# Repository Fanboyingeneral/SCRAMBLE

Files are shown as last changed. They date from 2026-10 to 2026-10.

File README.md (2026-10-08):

<div align="center">

# SCRAMBLE

**An autonomous Rubik's Cube solver driven by two bare-metal ATmega32 microcontrollers**

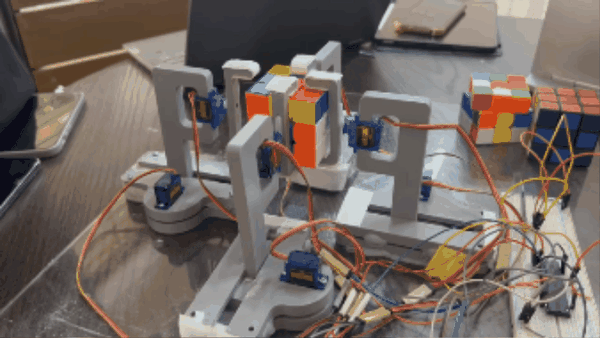
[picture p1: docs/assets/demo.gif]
SCRAMBLE turning a cube face










CSE 316 · Microcontrollers and Microprocessors

</div>

---

## Overview

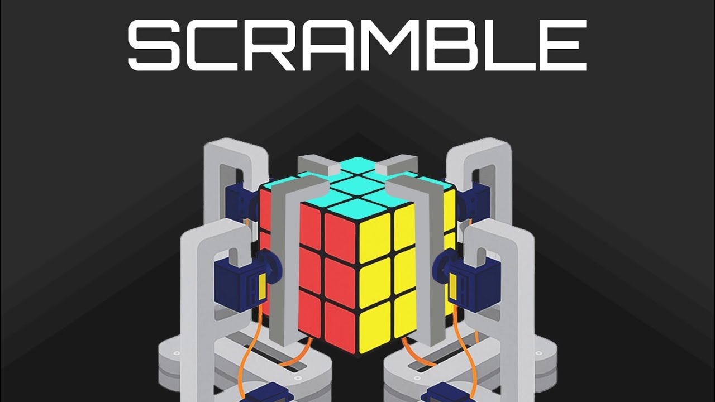
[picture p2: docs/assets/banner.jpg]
SCRAMBLE concept render


SCRAMBLE solves a scrambled 3×3 cube with no human input beyond the initial scan. An Android app reads the cube's state through the phone camera, a laptop computes a solution of at most 20 moves using Kociemba's two-phase algorithm, and the phone relays it over Bluetooth to a rig of eight servos controlled by two ATmega32s.

The firmware is written in plain AVR C against the hardware registers, without Arduino or any third-party libraries.

<br clear="right">

## System architecture

```mermaid
%%{init: {"theme": "base", "themeVariables": {"fontSize": "15px", "lineColor": "#64748b", "edgeLabelBackground": "#ffffff", "textColor": "#0f172a"}, "flowchart": {"curve": "basis", "nodeSpacing": 28, "rankSpacing": 60, "padding": 16}}}%%
flowchart LR
    subgraph PHONE["ANDROID APP"]
        direction TB
        CAM(["Camera scan"]) --> CONF{{"Confirm face"}}
        CONF -. "retake" .-> CAM
        CONF -- "accept ×6" --> STR["54-char facelet string"]
    end

    subgraph LAPTOP["SOLVER SERVER"]
        direction TB
        KOC[["Kociemba two-phase"]] --> SOL["≤ 20-move solution"]
    end

    subgraph RIG["ROBOT RIG"]
        direction TB
        HC(["HC-05 Bluetooth"]) --> M["ATmega32 master"]
        M -- "4 × PWM" --> TOP["4 turret servos · twist"]
        M -- "4 × GPIO" --> S["ATmega32 slave"]
        S -- "4 × PWM" --> BASE["4 base servos · grip"]
    end

    PHONE == "HTTP GET" ==> LAPTOP
    LAPTOP == "solution" ==> PHONE
    PHONE == "Bluetooth SPP" ==> RIG

    classDef app fill:#7c3aed,stroke:#4c1d95,stroke-width:2px,color:#ffffff
    classDef srv fill:#2563eb,stroke:#1e3a8a,stroke-width:2px,color:#ffffff
    classDef bt fill:#0284c7,stroke:#0c4a6e,stroke-width:2px,color:#ffffff
    classDef mcu fill:#0f766e,stroke:#134e4a,stroke-width:2px,color:#ffffff
    classDef servo fill:#f59e0b,stroke:#b45309,stroke-width:2px,color:#1f2937

    class CAM,CONF,STR app
    class KOC,SOL srv
    class HC bt
    class M,S mcu
    class TOP,BASE servo

    style PHONE fill:#f5f3ff,stroke:#7c3aed,stroke-width:2px,color:#5b21b6
    style LAPTOP fill:#eff6ff,stroke:#2563eb,stroke-width:2px,color:#1e40af
    style RIG fill:#f0fdfa,stroke:#0f766e,stroke-width:2px,color:#115e59

    linkStyle 0,1,2 stroke:#7c3aed,stroke-width:2px
    linkStyle 3 stroke:#2563eb,stroke-width:2px
    linkStyle 4,5,6,7 stroke:#0f766e,stroke-width:2px
    linkStyle 8,9 stroke:#2563eb,stroke-width:3px
    linkStyle 10 stroke:#0284c7,stroke-width:3px
```

1. **Scan.** The app guides the user through the faces in U, R, F, D, L, B order. It classifies each sticker by nearest RGB match and asks for confirmation, so a misread face can be retaken.
2. **Solve.** The six faces are serialised into Kociemba's 54-character facelet string and sent to the server, which returns a sequence such as `F2 U3 B2 D1 … (20f)`. The digit is the number of clockwise quarter turns.
3. **Execute.** The phone streams the moves to the HC-05. The master translates each one into a timed sequence of grips and twists shared across both controllers.

## Hardware

| Qty | Component | Role |
|:-:|---|---|
| 2 | ATmega32, internal 1 MHz oscillator | Master and slave controllers |
| 1 | HC-05 Bluetooth module | UART bridge to the phone, 9600 baud |
| 4 | Turret servo (SG90 class) | Rotates a face by 90° |
| 4 | Base servo | Drives a rack and pinion to grip or release |
| 4 | 3D-printed arm assemblies | See [`hardware/`](hardware/) |
| 1 | External 5 V supply | Servo power, common ground with both MCUs |

Four identical arms hold the F, B, L and R faces. Each arm has two degrees of freedom. The base servo turns a pinion along a rack, converting rotation into the linear motion that moves the claw onto or off the cube. The turret servo then rotates the gripped face. The U and D faces have no arm, so the rig reaches them by rolling the whole cube, performing an F turn, and rolling it back.

## Firmware

### Why two microcontrollers

Servos need a steady pulse train, and generating it in hardware keeps the timing jitter-free while the CPU services the UART. The ATmega32 has exactly four hardware PWM outputs:

| Timer | Width | Outputs | Pins |
|---|:-:|---|---|
| Timer 0 | 8-bit | OC0 | PB3 |
| Timer 1 | 16-bit | OC1A, OC1B | PD5, PD4 |
| Timer 2 | 8-bit | OC2 | PD7 |

That allows four servos per chip against the rig's eight. A second ATmega32 was preferred over software PWM or an external PCA9685 driver.

### PWM timing

All three timers run in fast PWM mode with the same period of about 16.4 ms (61 Hz). Timer 1 uses `ICR1 = 2048` with a prescaler of 8, which gives an 8 µs tick and fine positioning. Timers 0 and 2 use a prescaler of 64, giving a 64 µs tick. That coarser step is why their calibration values are small integers such as 7 and 24.

### Master–slave interface

Each base servo has only two positions, so the interface is four logic levels with no protocol at all. The slave polls them every 10 ms and updates its compare registers.

| Master | Slave | Base servo |
|:-:|:-:|---|
| PC0 | PC0 | Front |
| PC1 | PC1 | Back |
| PA2 | PC2 | Left |
| PA3 | PC3 | Right |

A HIGH level means grip and a LOW level means release. Both controllers share a common ground.

### Command set

| Byte | Action | Byte | Action |
|:-:|---|:-:|---|
| `F B L R` | Turret to 0° | `f b l r` | Turret to 90° |
| `W X Y Z` | Base release | `w x y z` | Base grip |
| `S` | Run the stored solve sequence | `A` | Test move (`U3`) |

The single-byte commands allow each servo to be jogged from a Bluetooth terminal, which is how the rig was calibrated. A quarter turn such as `R1` takes four steps: release, pre-rotate the empty claw, grip, then twist. Each step is followed by a 900 ms settling delay. Pin maps and calibration constants are in [`firmware/README.md`](firmware/README.md).

## Getting started

**Solver server**

```bash
cd solver-server
pip install numpy requests
python start_server.py 8080 20 3     # port, max moves, timeout in seconds
python test_client.py                # in a second terminal
```

The first launch generates about 70 MB of pruning tables, which takes several minutes. Later launches load them from disk.

**Android app.** Open [`android-app/`](android-app/) in Android Studio (SDK 36, minimum 24). Set the laptop's LAN address in `MainActivity.kt` under `sendRequestToServer()`, pair the phone with the HC-05, then build.

**Firmware**

```bash
cd firmware
make                 # builds master.hex and slave.hex
make flash-master    # USBasp by default
make flash-slave
```

Both chips run on the factory-default fuses. Calibrate the servo constants for your hardware before the first run.

## Repository structure

| Path | Contents |
|---|---|
| [`firmware/`](firmware/) | Master and slave controllers, Makefile |
| [`android-app/`](android-app/) | Scanner and controller app used in the demo |
| [`solver-server/`](solver-server/) | Kociemba's two-phase solver (vendored) and a test client |
| [`hardware/`](hardware/) | Print-ready STLs, FreeCAD sources, assembly drawings |
| [`docs/`](docs/) | Proposal decks and a [provenance map](docs/PROVENANCE.md) of the original working folder |
| [`archive/`](archive/) | Superseded prototypes and experiments, [catalogued here](archive/README.md) |
| [`coursework/`](coursework/) | Unrelated CSE 316 coursework |

## Development history

```mermaid
timeline
    title July 2025
    Jul 02 : Arm parts exported for printing, claw redesigned
    Jul 06 : Arduino reference design studied
    Jul 10 : Reference ported to ATmega32 C
    Jul 13 : Servo bring-up and calibration
    Jul 14 : Slave controller finalised
    Jul 23 : Camera scanner prototype
           : Manual-entry app with solver and Bluetooth
    Jul 26 : Master controller finalised
    Jul 28 : Final app
    Jul 29 : Demo
```

The project began from an open-source Arduino solver that ran a CFOP solver on the microcontroller and drove its servos through a PCA9685. Three decisions moved it away from that design:

- **Solving moved off the chip.** The two-phase algorithm caps solutions at 20 moves, and each move costs several seconds of servo time.
- **The PCA9685 was replaced by a second ATmega32**, which kept all servo control in native timer hardware.
- **Scanning kept a human in the loop.** An intermediate version used manual colour entry. The final app scans with the camera and asks for confirmation of each face.

## Known limitations

- The server address is hard-coded in the app.
- Colour references are tuned to one cube under one lighting setup.
- Motion is open-loop with fixed delays, so a failed grip goes undetected.

## Acknowledgements

- [**RubiksCube-TwophaseSolver**](https://github.com/hkociemba/RubiksCube-TwophaseSolver) by Herbert Kociemba (GPL-3.0), included unmodified in `solver-server/`.
- **Arduino-RubikSolver** (public domain), the source of the arm's FreeCAD design. We re-exported the parts for printing and redesigned the claw. A snapshot is kept in [`archive/upstream-reference/`](archive/upstream-reference/).

## Team

| Name | Student ID |
|---|:-:|
| Sakif Naieb Raiyan | 2105065 |
| Sayaad Muzahid Masfi | 2105066 |
| Aurchi Chowdhury | 2105083 |

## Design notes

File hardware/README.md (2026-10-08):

# 🔩 Hardware

| Folder | Contents |
|---|---|
| [`stl-print-ready/`](stl-print-ready/) | ⭐ **The STLs we printed.** Exported 2 Jul 2025. `Claw2.stl` is our redesigned claw |
| [`freecad-source/`](freecad-source/) | FreeCAD 0.17 sources for each part. Most are identical to the *Arduino-RubikSolver* project's `CAD/Final cuts` |
| [`blueprints/`](blueprints/) | Assembly and part drawings (PDF) from the same upstream project |

## One arm = 6 parts (×4 arms)

| Part | Job |
|---|---|
| `Base-bottom` / `Base-top` | Frame that holds the base servo and guides the rack |
| `Gear` | Pinion on the base servo horn |
| `Rack` | Slides in and out as the gear turns, turning **rotation into linear motion** |
| `Turret` | Rides on the rack and holds the turret servo |
| `Claw` | Mounted on the turret servo horn; grips and twists one face |

`servo-base.FCStd` and `cube.FCStd` (a reference cube for fitting) are in `freecad-source/`. An earlier STL export of every part, including the cube, is in [`../archive/hardware/stl-first-export/`](../archive/hardware/stl-first-export/).

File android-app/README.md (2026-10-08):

# 📱 SCRAMBLE Android app

The phone app used in the demo. It scans the cube, gets a solution from the laptop server and relays it to the rig over Bluetooth.

> The project and package are still called `RubiksCubeSolverWithoutCamera` / `com.example.rubikscubesolverwithoutcamera` for historical reasons. It started as a manual colour-entry app ([archive](../archive/android/02-manual-color-entry/)) and gained the camera later. Renaming the package is safe if you want to.

## Flow

```
Scan face ──▶ Confirm grid ──▶ (Retake | Accept) ──▶ … ×6 ──▶ GET solver ──▶ Solution screen
                                                                              ├─ Program  (sends "P")
                                                                              ├─ Send next move (e.g. "F2", last one gets ")")
                                                                              └─ Execute  (sends "S")
```

| Stage | Implementation |
|---|---|
| Camera | CameraX `Preview` + `ImageAnalysis` (keep-only-latest) |
| Sampling | 9 square ROIs at the centre of each grid cell, averaged RGB |
| Classification | Nearest neighbour (Euclidean RGB) against 6 reference colours |
| Face order | **U R F D L B**, which is Kociemba's facelet order |
| Colour scheme | U white · R blue · F red · D yellow · L green · B orange |
| Server call | OkHttp `GET http://<ip>:8080/<54 chars>`, solution parsed from `<body>` |
| Bluetooth | Bonded device named **`HC-05`**, insecure RFCOMM, SPP UUID `00001101-…-00805F9B34FB` |

## Configure

| What | Where |
|---|---|
| Laptop IP | `MainActivity.kt` → `sendRequestToServer()` (currently `172.20.10.12`) |
| Reference colours | `MainActivity.kt` → `referenceColorsRgb`. Tune these for your cube and lighting |
| Bluetooth name | `MainActivity.kt` → `sendBluetoothCommand()` → `deviceName` |

Cleartext HTTP to the LAN server is allowed through `res/xml/network_security_config.xml`.

## Build

Open this folder in Android Studio (compile/target SDK 36, min SDK 24) and run. Android Studio regenerates `local.properties`, which is git-ignored.

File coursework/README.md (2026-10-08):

# 📚 Coursework (not part of SCRAMBLE)

Other CSE 316 sessional material that lived in the same folder as the project. It's kept for completeness and has **no relation to the cube solver**.

| Folder | Contents |
|---|---|
| [`assembly-online-1/`](assembly-online-1/) | 8086 assembly solutions (emu8086) and the online question sheet |
| [`assembly-offlines/`](assembly-offlines/) | Assembly offline/online problem statements (PDF) |
| [`experiments/`](experiments/) | Lab experiment sheets (LED matrix, Experiment 2) and a demo deck |

The emu8086 installation, its build artifacts and the `Utilities` DLL were not copied. They remain in the raw source folder.

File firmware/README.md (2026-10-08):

# ⚙️ Firmware: ATmega32 master + slave

Bare-metal AVR C with direct register access and no Arduino core. Both chips run on the **internal 1 MHz RC oscillator** (factory fuses).

| File | Chip | Drives |
|---|---|---|
| [`master/master_controller.c`](master/master_controller.c) | Master | HC-05 UART, 4 turret servos, 4 lines to the slave, move choreography |
| [`slave/slave_controller.c`](slave/slave_controller.c) | Slave | 4 base (grip) servos, mirroring the master's 4 lines |

## Build and flash

Requires `avr-gcc`, `avr-libc` and `avrdude` (or Microchip Studio).

```bash
make                 # → master.hex, slave.hex
make flash-master    # default programmer: USBasp
make flash-slave
make flash-master PROGRAMMER=stk500v1 PORT=COM5   # override
```

## Why 4 servos per chip

The ATmega32 has four hardware PWM outputs: **OC0** (PB3), **OC1A** (PD5), **OC1B** (PD4) and **OC2** (PD7). Timer 1 is 16-bit and drives two of them. Timers 0 and 2 are 8-bit and drive one each. Eight servos therefore need two chips.

## PWM configuration

```c
// Timer 1: Fast PWM, TOP = ICR1 (mode 14), prescaler 8 → 8 µs/tick, 2049 ticks ≈ 16.4 ms
TCCR1A = (1<<WGM11) | (1<<COM1A1) | (1<<COM1B1);
TCCR1B = (1<<WGM13) | (1<<WGM12) | (1<<CS11);
ICR1   = 2048;

// Timer 2: Fast PWM 8-bit, prescaler 64 → 64 µs/tick, 256 ticks ≈ 16.4 ms
TCCR2 = (1<<WGM21) | (1<<WGM20) | (1<<COM21) | (1<<CS22);

// Timer 0: Fast PWM 8-bit, prescaler 64 → same 16.4 ms frame
TCCR0 = (1<<WGM01) | (1<<WGM00) | (1<<COM01) | (1<<CS01) | (1<<CS00);
```

Pulse width = `OCRx × tick`. For example, `OCR1B = 75` gives 600 µs and `OCR1B = 210` gives 1.68 ms.

## Calibration constants

Measured on our rig. **Re-measure these for yours.**

| Servo | Register | 0° / min | 90° / max |
|---|---|:-:|:-:|
| Turret Front | master `OCR1B` | 75 | 210 |
| Turret Back | master `OCR1A` | 78 | 204 |
| Turret Left | master `OCR2` | 7 | 24 |
| Turret Right | master `OCR0` | 8 | 24 |
| Base Front | slave `OCR1B` | 70 | 230 |
| Base Back | slave `OCR1A` | 120 | 280 |
| Base Left | slave `OCR2` | 10 | 30 |
| Base Right | slave `OCR0` | 10 | 30 |

Use the single-byte jog commands (`F`/`f`, `W`/`w`, …) from a Bluetooth serial terminal to find each value.

## Master → slave wiring

| Master | Slave | Base servo |
|:-:|:-:|---|
| PC0 | PC0 | Front |
| PC1 | PC1 | Back |
| PA2 | PC2 | Left |
| PA3 | PC3 | Right |
| GND | GND | *common ground* |

> The header comment in `master_controller.c` says PC0–PC3, but the code drives **PC0, PC1, PA2, PA3**. The table above follows the code.

## Move notation

The solver outputs moves as `<face><n>`, where `n` is the number of clockwise quarter turns (`1` = 90°, `2` = 180°, `3` = 270°, i.e. counter-clockwise). `execute_sequence()` parses that format directly and stops at `(` (the `(20f)` length suffix).

| Move | Implementation |
|---|---|
| `F` `B` `L` `R` + 1/2/3 | Release → pre-rotate → grip → twist, using the face's own arm |
| `U` + n | `Rotate_top()` → `F` + n → `Rotate_bottom()` |
| `D` + n | `Rotate_bottom()` → `F` + n → `Rotate_top()` |

Each primitive step is followed by `_delay_ms(900)`.

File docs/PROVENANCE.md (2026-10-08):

# 🧭 Provenance: raw folder → repo

This repo was assembled from the original, unorganised `CSE 316/` working folder, which is preserved untouched. The tables below show where everything came from and what was deliberately left out.

## Copied

| Raw path | Repo path |
|---|---|
| `maxresdefault.jpg` | `docs/assets/banner.jpg` |
| `Project/Project Proposal Presentation.pdf`, `Project/Updated Proposal.pdf` | `docs/proposal/` |
| `Project/Arduino-RubikSolver-master/arduino files/a_constants/master_controller.c` | `firmware/master/` |
| `Project/Arduino-RubikSolver-master/arduino files/a_constants/slave_controller.c` | `firmware/slave/` |
| `RubiksCubeSolverWithoutCamera/` | `android-app/` |
| `Project_Web_Server/RubiksCube-TwophaseSolver-master/` | `solver-server/` (`README.md` → `UPSTREAM_README.md`) |
| `Project_Web_Server/test_client.py` | `solver-server/test_client.py` |
| `Project/Print Ready 3D Files/` | `hardware/stl-print-ready/` |
| `Project/Original 3D Files/` | `hardware/freecad-source/` |
| `Project/rubick-*.pdf` | `hardware/blueprints/` |
| `Project_Android_App/` | `archive/android/01-camera-hsv-client/` |
| `FinalVersionAttempt_v1/` | `archive/android/02-manual-color-entry/` |
| `BluetoothTestApp/` | `archive/android/03-bluetooth-test/` |
| `…/a_constants/*_atmega32.c` (except motor tests) | `archive/firmware/atmega32-cfop-port/` |
| `…/a_constants/{top_motors,base_motors,new_task}_atmega32.c` | `archive/firmware/motor-tests/` |
| `…/arduino files/Solver/solver.py` | `archive/firmware/solver-smoke-test/` |
| `Project/3D Files/All3D_stl/` | `archive/hardware/stl-first-export/` |
| `Project/6190212806561875445.jpg`, `Project/c3RlZCZ3PTc0MA.png` | `archive/proposal-assets/` |
| `Project/Arduino-RubikSolver-master/` (sources, CAD, blueprints, photos) | `archive/upstream-reference/Arduino-RubikSolver/` |
| `Online Prep/Online 1/*.asm`, `Online q.pdf` | `coursework/assembly-online-1/` |
| `Offlines/*.pdf` | `coursework/assembly-offlines/` |
| `Experiments/*.pdf`, `demo.pptx` | `coursework/experiments/` |

## Not copied (still in the raw folder)

| Raw path | Why |
|---|---|
| `Project/Final Demo.mov` (569 MB) | Over GitHub's 100 MB limit. It's [on YouTube](https://youtu.be/4RdSLmTVIiQ) |
| `Project/arduino-ide_nightly-…zip` (196 MB) | Third-party installer |
| `emu8086/`, `emu8086v408r.exe` | Third-party tool installation |
| `Experiments/Utilities*` | Third-party binary |
| `Project/IMG_20190305_233856.jpg` | Duplicate of an upstream photo (kept in `archive/upstream-reference/…/CAD/photos/`) |
| `Project/3D Files/All3D_stl.zip` | Zip of `All3D_stl/`, which is copied unzipped |
| `Project/Atmel/` | Empty |
| Upstream `android App/java/` + native libs (~1.5 GB) | Bundled OpenCV Android SDK |
| Upstream `CAD/CNC cutting media/*.mp4` (~230 MB) | Upstream build videos |
| Upstream `arduino files/Solver/` tables, `Project_Web_Server/…/twophase/` (~70 MB each) | Generated solver tables; rebuilt on first run |
| `Online Prep/Online 1/noname.exe*` | emu8086 build artifacts and backups |
| `build/`, `.gradle/`, `.idea/`, `.kotlin/`, `__pycache__/`, `local.properties` | Generated or machine-specific |

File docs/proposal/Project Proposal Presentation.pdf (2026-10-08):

# Scramble

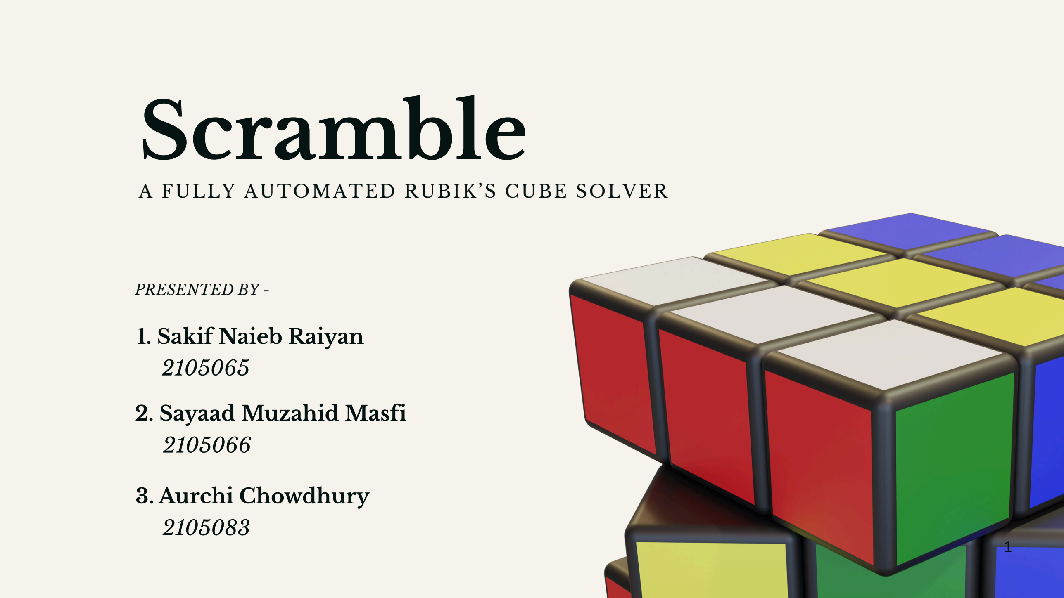
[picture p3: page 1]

A FULLY AUTOMATED RUBIK’S CUBE SOLVER

PRESENTED BY -

1

### 1. Sakif Naieb Raiyan

2105065

### 2. Sayaad Muzahid Masfi

### 3. Aurchi Chowdhury

2105066

2105083

# MOTIVATION

2

## PROBLEM STATEMENT

DESIGN AND DEVELOP AN AUTOMATED RUBIK’S CUBE SOLVER USING A MICROCONTROLLER-BASED SYSTEM THAT CAN PHYSICALLY MANIPULATE THE CUBE AND TRACK SOLVE TIME, WITH USER INPUT PROVIDED VIA A MOBILE INTERFACE

3

## SIGNIFICANCE

4

The Rubik’

s Cube is a globally recognized puzzle that represents a challenge in both logic and dexterity.

Automating its solution not only demonstrates practical applications of embedded systems, robotics, and computer vision, but also showcases how mechanical and software components can work together to solve complex problems.

This project bridges the gap between theoretical concepts and real-world implementation, making it an excellent learning opportunity in the fields of mechatronics and embedded systems.

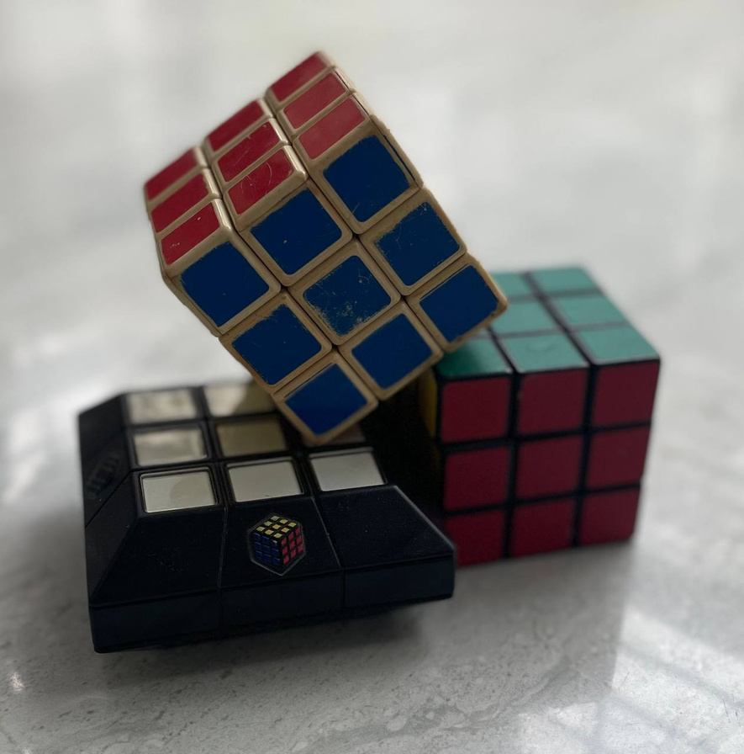
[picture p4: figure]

## PERSONAL INTEREST

5

All three of us were fascinated by the Rubik’

s Cube back in 7th grade, when we each owned multiple and took the time to learn how to solve it.
That early interest sparked our curiosity in problem-solving and logical thinking, and eventually inspired this project. This project is especially interesting to us as it showcases how a childhood curiosity can grow into an engineering challenge.

One of our team members dug up some of his old Rubik’

s cubes

# EQUIPMENT

6

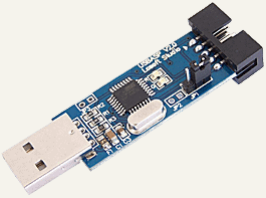
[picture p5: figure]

USBASP

3

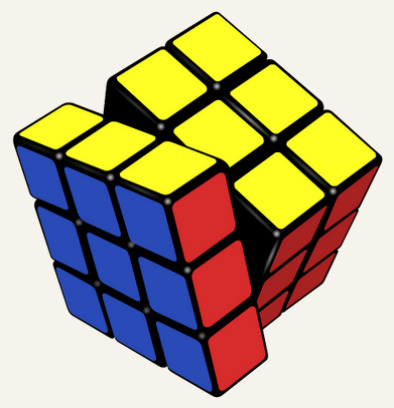
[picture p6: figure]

Rubik’

s Cube

1

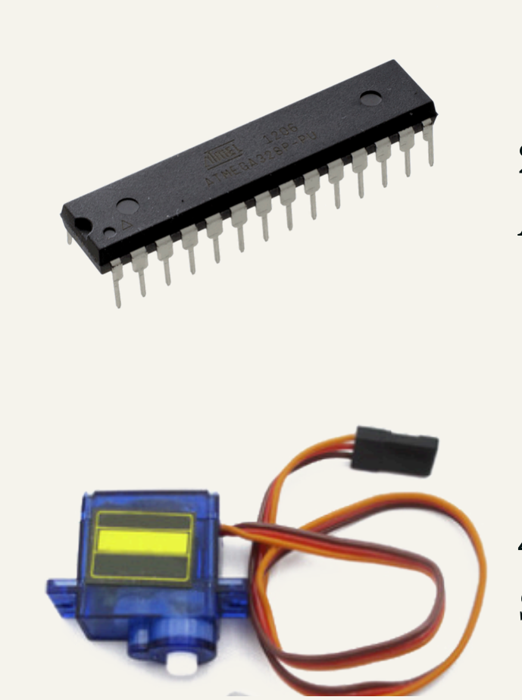
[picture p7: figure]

SG90 Servo Motor

4

ATMega32

2

## Hardware List

7

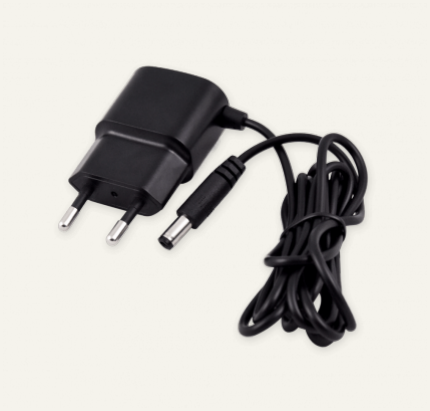
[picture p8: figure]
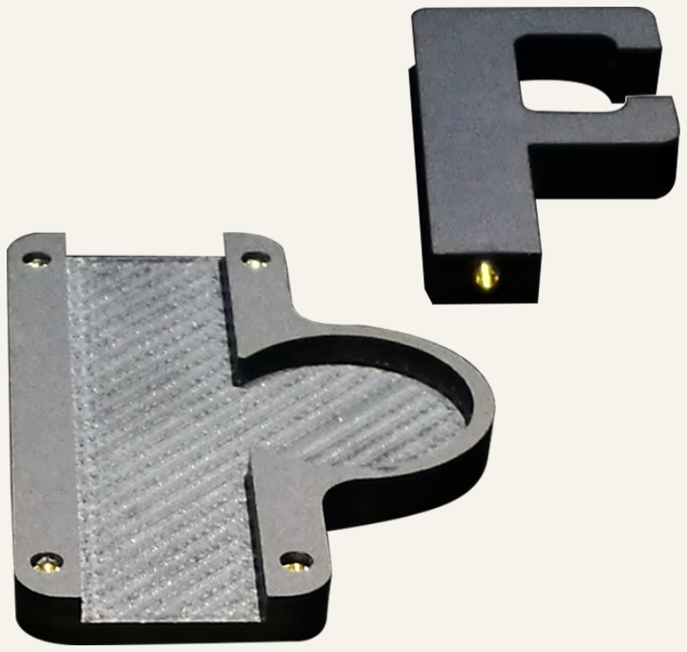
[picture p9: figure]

8

Power Supply

7

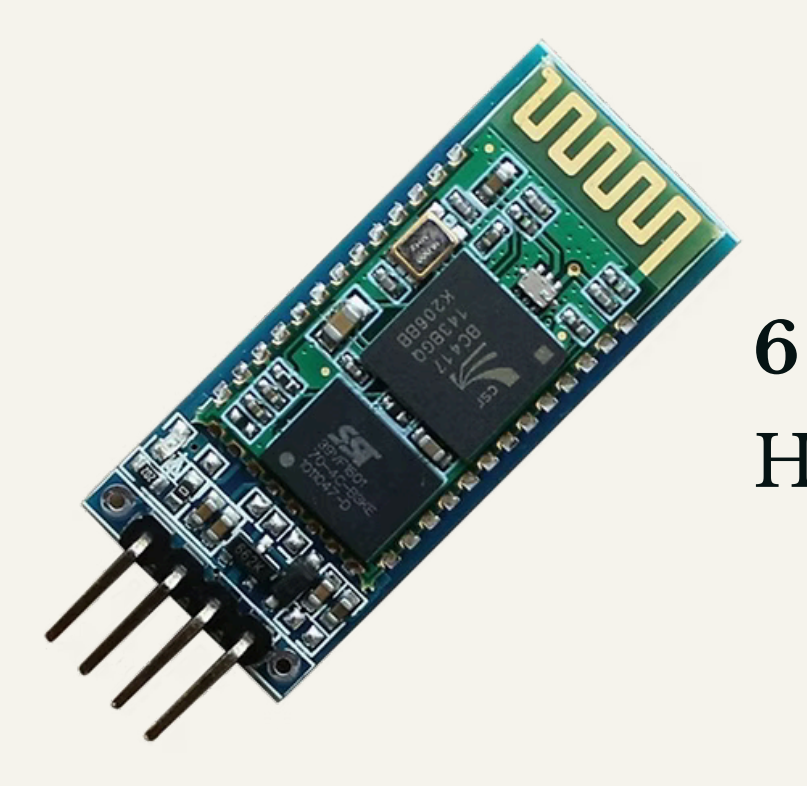
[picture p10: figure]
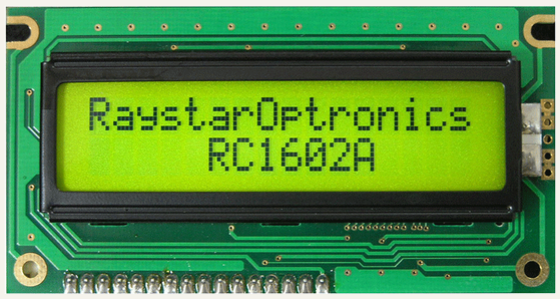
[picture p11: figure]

LCD 16x2 Display

5

Acrylic Printed
Mechanical Arm

8

HC-06 Bluetooth Module

## Hardware List

# SCHEMATIC

9

## HIGH LEVEL DIAGRAM

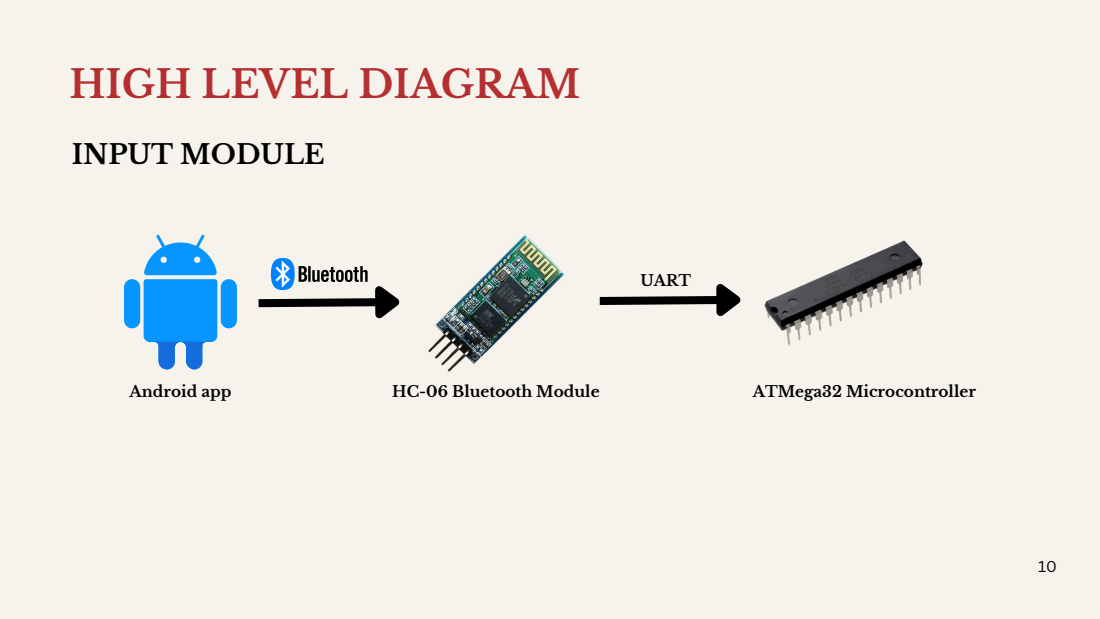
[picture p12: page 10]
Android app; HC-06 Bluetooth Module; UART; ATMega32 Microcontroller; INPUT MODULE

11

## HIGH LEVEL DIAGRAM

PROCESSING AND OUTPUT MODULE

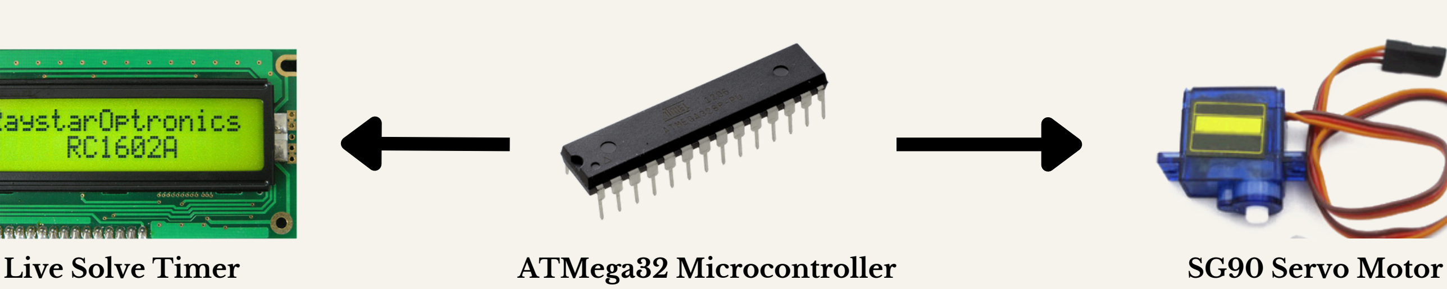
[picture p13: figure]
ATMega32 Microcontroller; Live Solve Timer; SG90 Servo Motor
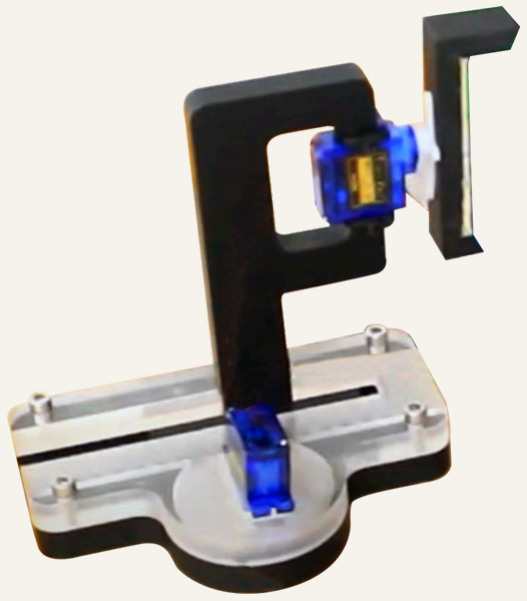
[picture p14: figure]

Mechanical Arm

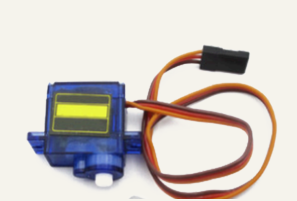
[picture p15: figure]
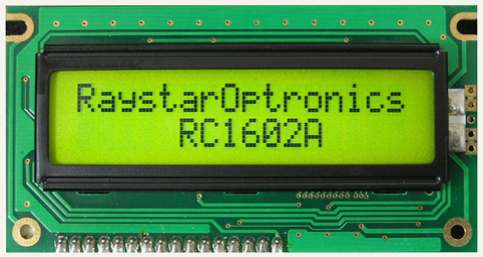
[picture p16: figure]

12

# Explanation

Android App: Captures the initial state of the Rubik’

s
Cube using the phone camera and sends the color configuration to the microcontroller via Bluetooth. HC-06 Bluetooth Module: Acts as a wireless communication bridge between the Android app and the ATmega32 microcontroller using UART.
ATmega32 Microcontroller: The core of the system that receives input from the Bluetooth module, calculates the solution (or controls motors based on a received solve sequence), and drives the mechanical components.

13

# Explanation

LCD Timer Display: Displays the time taken to complete the solve and updates live during operation. Servo/Stepper Motors: Physically manipulate the Rubik’

s Cube to perform the solving moves. Power Supply: Provides appropriate voltage and current to all electronic components and motors.
Mechanical Arm (Acrylic Structure): Holds and rotates the Rubik’

s Cube based on motor control, built from custom-cut acrylic sheets.

14

# PROCESS

15

# Expected Outcome

The final project is expected to successfully scan the state of a standard 3×3 Rubik’

s Cube, compute the optimal or near-optimal solution using a solving algorithm, and physically solve the cube using motors controlled by an ATMega32 microcontroller.

# Step-by-Step Plan

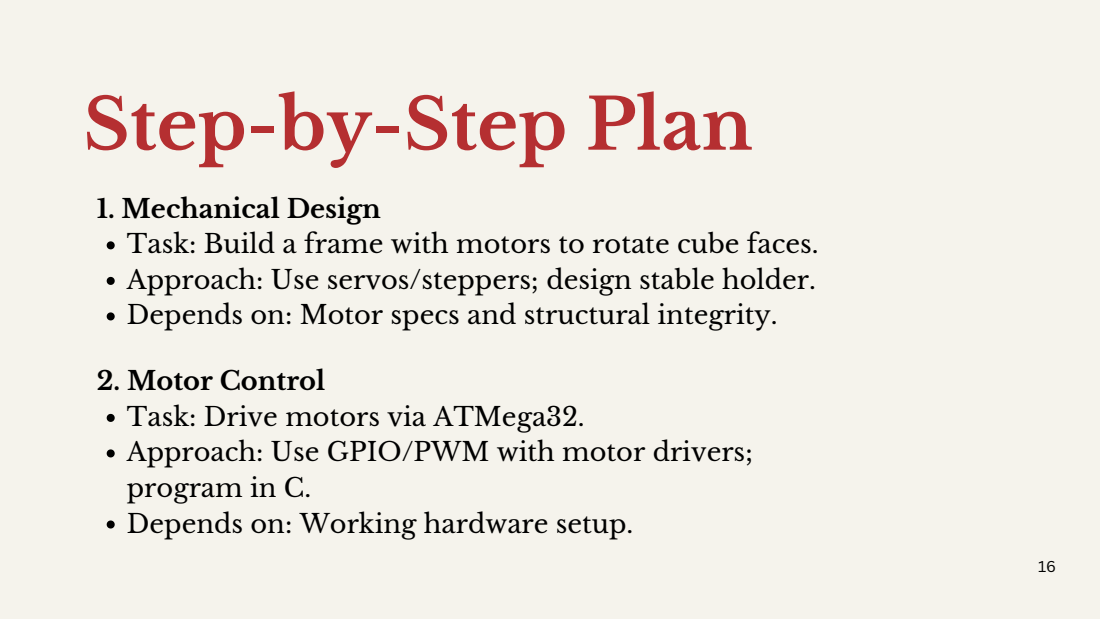
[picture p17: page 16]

1. Mechanical Design
Task: Build a frame with motors to rotate cube faces.
Approach: Use servos/steppers; design stable holder.
Depends on: Motor specs and structural integrity.

2. Motor Control
Task: Drive motors via ATMega32.
Approach: Use GPIO/PWM with motor drivers;
program in C.
Depends on: Working hardware setup.

# Step-by-Step Plan

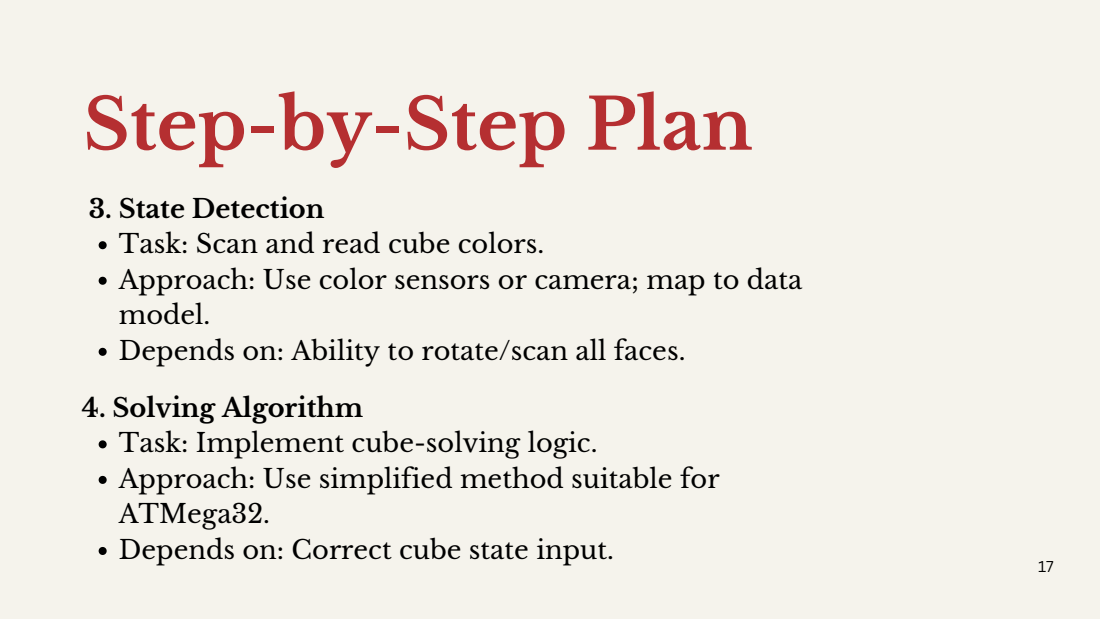
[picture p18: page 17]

3. State Detection
Task: Scan and read cube colors.
Approach: Use color sensors or camera; map to data
model.
Depends on: Ability to rotate/scan all faces.
4. Solving Algorithm
Task: Implement cube-solving logic.
Approach: Use simplified method suitable for
ATMega32.
Depends on: Correct cube state input.

# Step-by-Step Plan

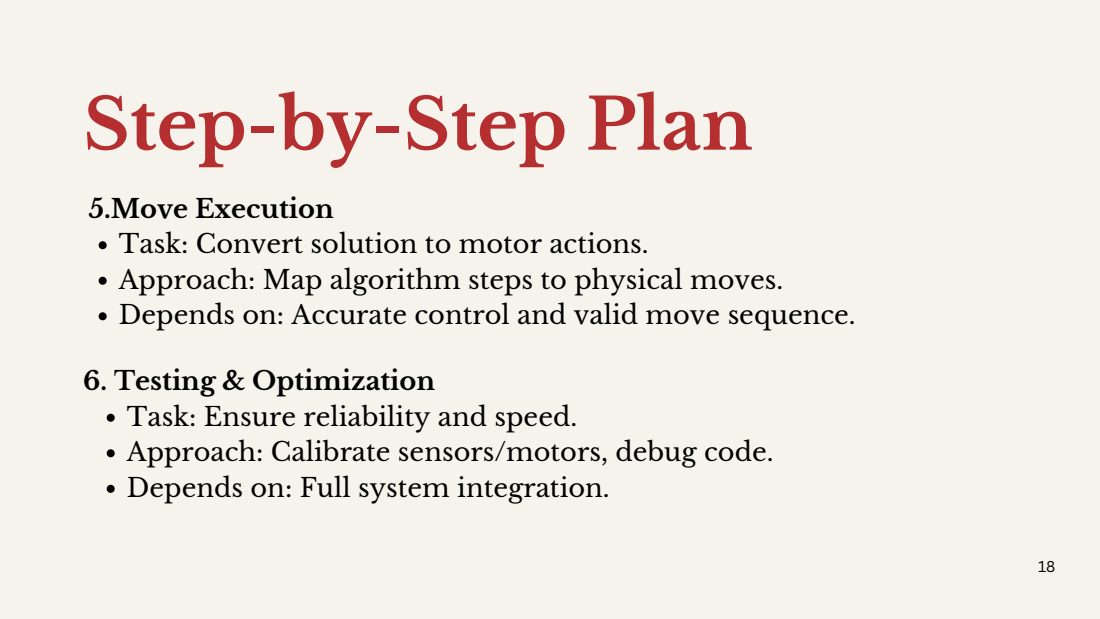
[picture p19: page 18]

5.Move Execution
Task: Convert solution to motor actions.
Approach: Map algorithm steps to physical moves.
Depends on: Accurate control and valid move sequence.

6. Testing & Optimization
Task: Ensure reliability and speed.
Approach: Calibrate sensors/motors, debug code.
Depends on: Full system integration.

# CHALLENGES AND FUTURE DIRECTIONS

19

# Challenges

### 1. Motor Control and Precision 2. Building and Assembling the Mechanical Parts 3. Cube State Detection 4. Processing Limitations of ATMega32

20

21

# Future Scope

## Scalability and Optimization

The project could be enhanced to support faster solve times through optimized algorithms or by upgrading to a more powerful microcontroller while maintaining the ATMega32 for simpler tasks.

22

# Future Scope

## Integrating Advanced Visualization Systems and UI

Adding a small display or mobile app interface could allow users to interact with the system, view solving steps, or select different solving modes

23

# Future Scope

## Real-World Applications Beyond the Classroom

STEM Demonstration: Can be used in robotics clubs, science fairs, or tech exhibitions to demonstrate automation and embedded system applications.

Educational Tool: Helps in teaching control systems, embedded programming, and algorithms.

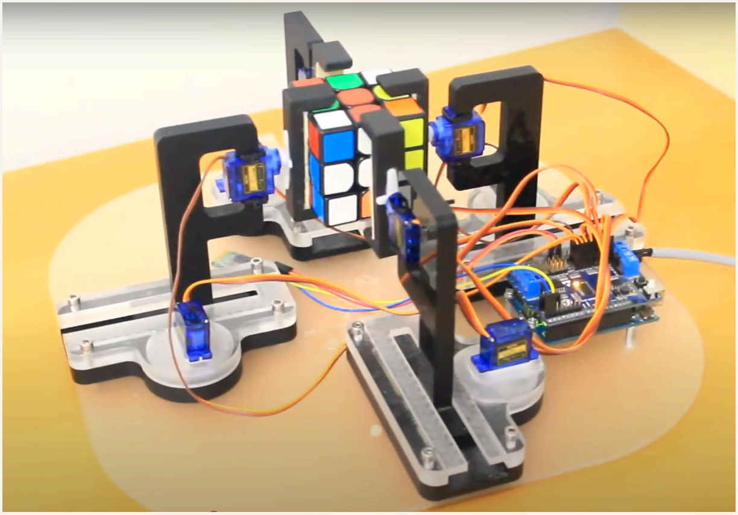
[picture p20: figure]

24

# Inspiration From

Links to the-YouTube video (https://www.youtube.com/watch?v=ZHaAKOHkDEo&t=1s&ab_channel=Eman)
Github Repository (https://github.com/EmanGM/Arduino-RubikSolver)

25

# THANK YOU!

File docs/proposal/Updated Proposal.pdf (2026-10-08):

# Scramble


A FULLY AUTOMATED RUBIK’S CUBE SOLVER

PRESENTED BY -

1

### 1. Sakif Naieb Raiyan

2105065

### 2. Sayaad Muzahid Masfi

### 3. Aurchi Chowdhury

2105066

2105083

# MOTIVATION

2

## PROBLEM STATEMENT

DESIGN AND DEVELOP AN AUTOMATED RUBIK’S CUBE SOLVER USING A MICROCONTROLLER-BASED SYSTEM THAT CAN PHYSICALLY MANIPULATE THE CUBE AND TRACK SOLVE TIME, WITH USER INPUT PROVIDED VIA A MOBILE INTERFACE

3

## SIGNIFICANCE

4

The Rubik’

s Cube is a globally recognized puzzle that represents a challenge in both logic and dexterity.

Automating its solution not only demonstrates practical applications of embedded systems, robotics, and computer vision, but also showcases how mechanical and software components can work together to solve complex problems.

This project bridges the gap between theoretical concepts and real-world implementation, making it an excellent learning opportunity in the fields of mechatronics and embedded systems.


## PERSONAL INTEREST

5

All three of us were fascinated by the Rubik’

s Cube back in 7th grade, when we each owned multiple and took the time to learn how to solve it.
That early interest sparked our curiosity in problem-solving and logical thinking, and eventually inspired this project. This project is especially interesting to us as it showcases how a childhood curiosity can grow into an engineering challenge.

One of our team members dug up some of his old Rubik’

s cubes

# EQUIPMENT

6


USBASP

3


Rubik’

s Cube

1


SG90 Servo Motor

4

ATMega32

2

## Hardware List

7


8

Power Supply

7


LCD 16x2 Display

5

Acrylic Printed
Mechanical Arm

8

HC-05 Bluetooth Module

## Hardware List

# SCHEMATIC

9

## HIGH LEVEL DIAGRAM

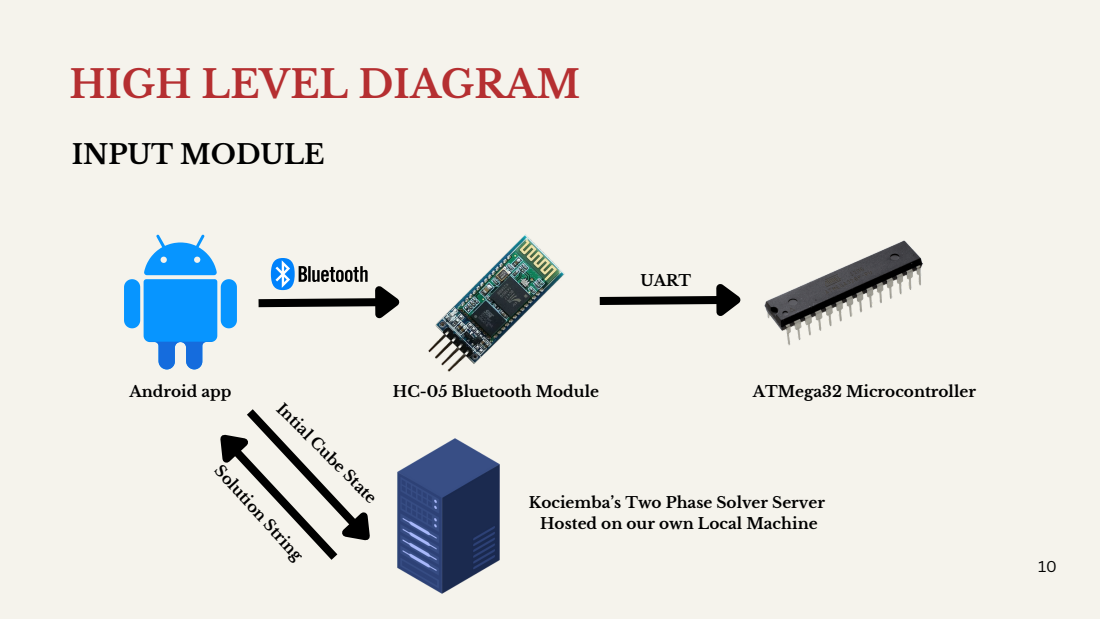
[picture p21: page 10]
Android app; HC-05 Bluetooth Module; UART; ATMega32 Microcontroller; INPUT MODULE; Solution String

Intial Cube State

Kociemba’s Two Phase Solver Server
Hosted on our own Local Machine

11

## HIGH LEVEL DIAGRAM

PROCESSING AND OUTPUT MODULE

ATMega32 Microcontroller; Live Solve Timer; SG90 Servo Motor

Mechanical Arm


12

# Explanation

Android App: Captures the initial state of the Rubik’

s
Cube using the phone camera and sends the color configuration to the microcontroller via Bluetooth. HC-06 Bluetooth Module: Acts as a wireless communication bridge between the Android app and the ATmega32 microcontroller using UART.
ATmega32 Microcontroller: The core of the system that receives input from the Bluetooth module, calculates the solution (or controls motors based on a received solve sequence), and drives the mechanical components.

13

# Explanation

LCD Timer Display: Displays the time taken to complete the solve and updates live during operation. Servo/Stepper Motors: Physically manipulate the Rubik’

s Cube to perform the solving moves. Power Supply: Provides appropriate voltage and current to all electronic components and motors.
Mechanical Arm (Acrylic Structure): Holds and rotates the Rubik’

s Cube based on motor control, built from custom-cut acrylic sheets.

14

# PROCESS

15

# Expected Outcome

The final project is expected to successfully scan the state of a standard 3×3 Rubik’

s Cube, compute the optimal or near-optimal solution using a solving algorithm, and physically solve the cube using motors controlled by an ATMega32 microcontroller.

# Step-by-Step Plan


1. Mechanical Design
Task: Build a frame with motors to rotate cube faces.
Approach: Use servos/steppers; design stable holder.
Depends on: Motor specs and structural integrity.

2. Motor Control
Task: Drive motors via ATMega32.
Approach: Use GPIO/PWM with motor drivers;
program in C.
Depends on: Working hardware setup.

# Step-by-Step Plan


3. State Detection
Task: Scan and read cube colors.
Approach: Use color sensors or camera; map to data
model.
Depends on: Ability to rotate/scan all faces.
4. Solving Algorithm
Task: Implement cube-solving logic.
Approach: Use simplified method suitable for
ATMega32.
Depends on: Correct cube state input.

# Step-by-Step Plan


5.Move Execution
Task: Convert solution to motor actions.
Approach: Map algorithm steps to physical moves.
Depends on: Accurate control and valid move sequence.

6. Testing & Optimization
Task: Ensure reliability and speed.
Approach: Calibrate sensors/motors, debug code.
Depends on: Full system integration.

# CHALLENGES AND FUTURE DIRECTIONS

19

# Challenges

### 1. Motor Control and Precision 2. Building and Assembling the Mechanical Parts 3. Cube State Detection 4. Processing Limitations of ATMega32

20

21

# Future Scope

## Scalability and Optimization

The project could be enhanced to support faster solve times through optimized algorithms or by upgrading to a more powerful microcontroller while maintaining the ATMega32 for simpler tasks.

22

# Future Scope

## Integrating Advanced Visualization Systems and UI

Adding a small display or mobile app interface could allow users to interact with the system, view solving steps, or select different solving modes

23

# Future Scope

## Real-World Applications Beyond the Classroom

STEM Demonstration: Can be used in robotics clubs, science fairs, or tech exhibitions to demonstrate automation and embedded system applications.

Educational Tool: Helps in teaching control systems, embedded programming, and algorithms.


24

# Inspiration From

Links to the-YouTube video (https://www.youtube.com/watch?v=ZHaAKOHkDEo&t=1s&ab_channel=Eman)
Github Repository (https://github.com/EmanGM/Arduino-RubikSolver)

25

# MEET THE TEAM

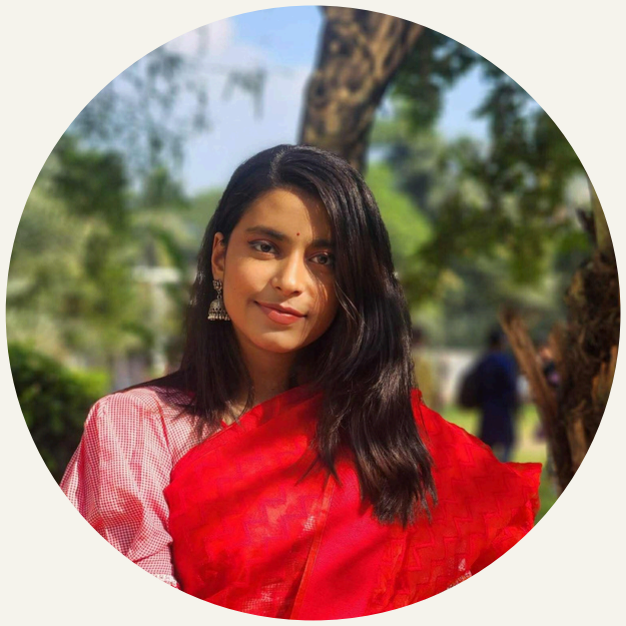
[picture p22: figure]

Aurchi Chowdhury
2105083

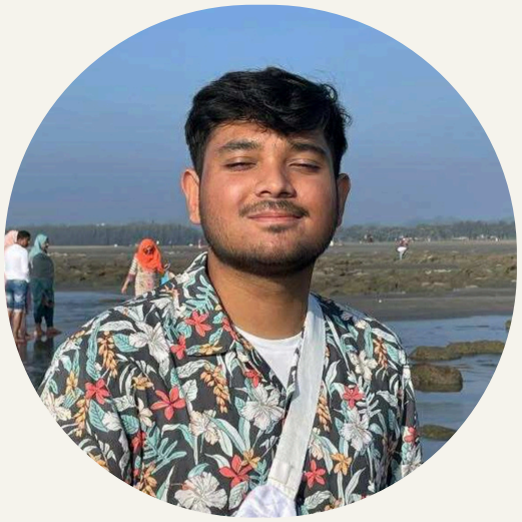
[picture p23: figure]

Sakif Naieb Raiyan
2105065

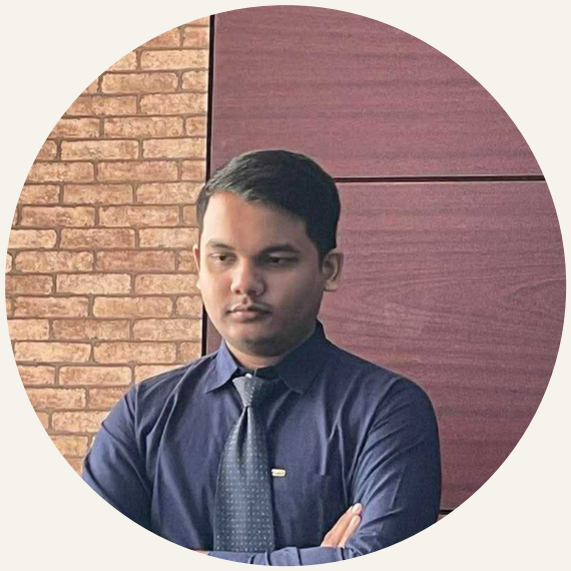
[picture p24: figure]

Sayaad Muzahid Masfi
2105066

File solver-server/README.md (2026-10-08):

# 🧠 Solver server

This is **[Herbert Kociemba's RubiksCube-TwophaseSolver](https://github.com/hkociemba/RubiksCube-TwophaseSolver)**, vendored **unmodified** and licensed under **GPL-3.0** (see [`LICENSE`](LICENSE)). The original documentation is in [`UPSTREAM_README.md`](UPSTREAM_README.md).

The only SCRAMBLE addition is [`test_client.py`](test_client.py).

## Run

```bash
pip install numpy requests
python start_server.py 8080 20 3    # port, max solution length, search timeout (s)
```

The first start generates the pruning and move tables (~70 MB) into `twophase/`. This takes a while and only happens once. The folder is git-ignored.

## API

```
GET http://<host>:8080/<54-char facelet string in URFDLB order>
→ <html>…<body>F2 U3 F2 U3 B2 D1 L2 U2 F2 L1 B3 L1 F3 U1 B3 D1 L3 F3 R1 B1 (20f)</body></html>
```

## Test

```bash
python test_client.py
```

This sends a fixed scramble to `localhost:8080` and prints the solution.

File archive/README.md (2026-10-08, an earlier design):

# 🧪 Archive: explorations and dead ends

**Nothing in this folder is part of the final SCRAMBLE build.** These are the experiments, ports and test apps that led to it. They are kept because they show how the design evolved, and some (like the motor tests) are handy for bring-up.

Legend: 🟢 directly led to the final design · 🟡 partly reused · 🔴 abandoned · 📖 third-party reference

---

## 📱 `android/`

| Folder | Date | Status | What it is |
|---|---|:-:|---|
| [`01-camera-hsv-client/`](android/01-camera-hsv-client/) | 23 Jul | 🟡 | **First app** (`RubiksSolverClient`). CameraX scanner that *learns* reference colours in a calibration pass (HSV), then scans. Scanning only: no solver call and no Bluetooth yet. The camera and ROI code were carried into the final app |
| [`02-manual-color-entry/`](android/02-manual-color-entry/) | 23–26 Jul | 🟡 | **`FinalVersionAttempt_v1`**. Drops the camera: you tap stickers on a grid with a colour palette. Adds the solver HTTP call and HC-05 Bluetooth sending. The final app is this project plus the camera back. That's where the name *RubiksCubeSolverWithoutCamera* comes from |
| [`03-bluetooth-test/`](android/03-bluetooth-test/) | 26 Jul | 🟢 | Minimal one-button app that sends `Z` to a paired module (originally `HC-06`). Used to prove the phone → UART link |

## 🔌 `firmware/`

| Folder | Date | Status | What it is |
|---|---|:-:|---|
| [`motor-tests/`](firmware/motor-tests/) | 13 Jul | 🟢 | Single-chip bring-up for the servos. `new_task_atmega32.c` sweeps each turret servo. `top_motors_atmega32.c` jogs turret servos over Bluetooth. `base_motors_atmega32.c` jogs base servos with 2-char commands. These became the master and slave |
| [`atmega32-cfop-port/`](firmware/atmega32-cfop-port/) | 10 Jul | 🔴 | A line-by-line port of the Arduino reference to AVR C: on-chip cube model, CFOP solver (Cross/F2L/OLL/PLL), colour-sensor reading, PCA9685 servo driver over I²C, serial menu. Dropped in favour of off-board Kociemba solving and native timer PWM on two chips |
| [`solver-smoke-test/`](firmware/solver-smoke-test/) | Jul | 🟡 | Three-line script that called `twophase.solver` directly before the HTTP server was used |

## 🛠 `hardware/`

| Folder | Status | What it is |
|---|:-:|---|
| [`stl-first-export/`](hardware/stl-first-export/) | 🟡 | First STL export of all parts, including the reference cube. Superseded by `hardware/stl-print-ready/` |

## 🖼 `proposal-assets/`

Mood-board images used in the proposal deck. `robot-arm-freepik.png` is Freepik stock (attribution in the image).

## 📖 `upstream-reference/Arduino-RubikSolver/`

A **source-only snapshot** of the open-source *Arduino-RubikSolver* project (public domain, see its [`LICENSE`](upstream-reference/Arduino-RubikSolver/LICENSE)). This is where we started. It contains:

- `arduino/`: the original `.ino` sketches (the source of the `atmega32-cfop-port` above)
- `android-app/src/`: its Kotlin app (camera colour sensing + Bluetooth)
- `CAD/`: FreeCAD 2D/3D files and photos of CNC-cut parts
- `blueprints/`: assembly drawings

Stripped from the snapshot to keep the repo small: the bundled OpenCV Android SDK (~1.5 GB), build outputs, and ~230 MB of CNC cutting videos. These are still available in the raw source folder.

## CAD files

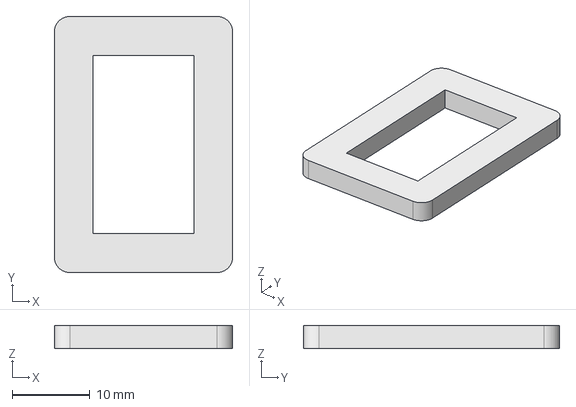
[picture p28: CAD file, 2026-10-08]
hardware/freecad-source/servo-base.FCStd
23.0 x 33.0 x 3.00 mm

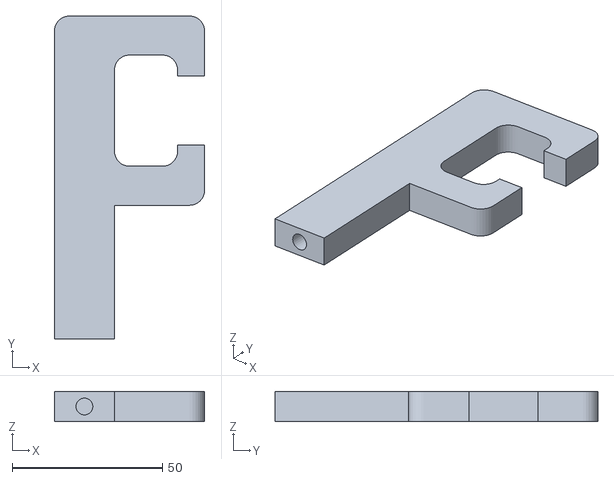
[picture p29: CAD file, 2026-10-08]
hardware/stl-print-ready/Turret.stl
50.0 x 107.5 x 10.0

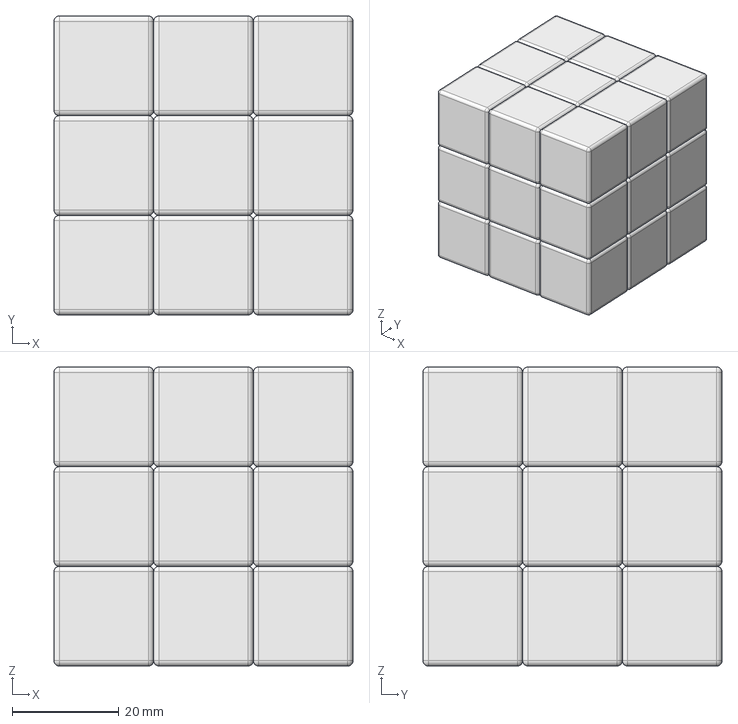
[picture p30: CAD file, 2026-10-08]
hardware/freecad-source/cube.FCStd
56.1 x 56.1 x 56.1 mm

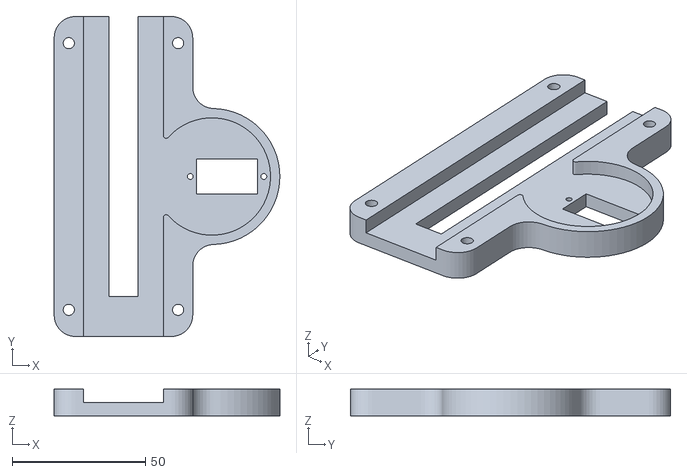
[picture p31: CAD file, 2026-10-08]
hardware/stl-print-ready/Base-top.stl
84.7 x 120.0 x 10.0

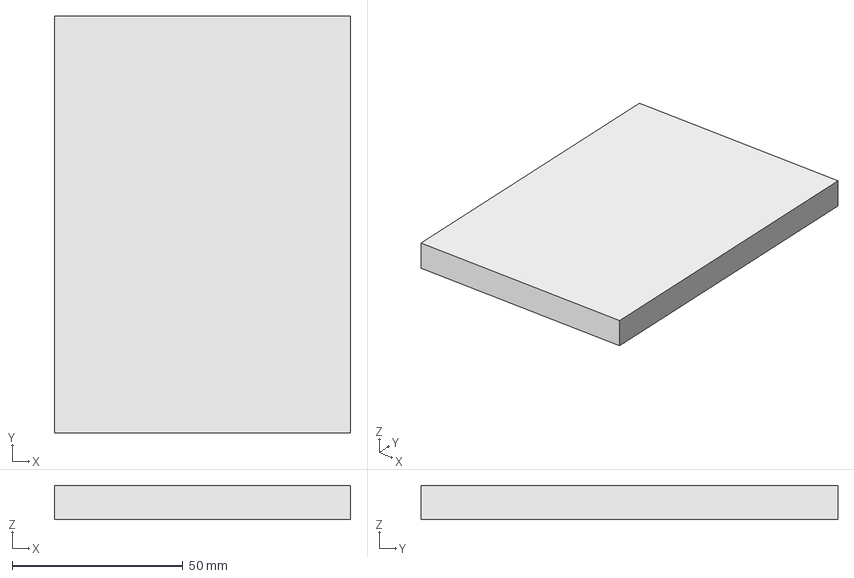
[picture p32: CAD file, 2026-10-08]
hardware/freecad-source/base-top.FCStd
86.7 x 122.0 x 10.0 mm

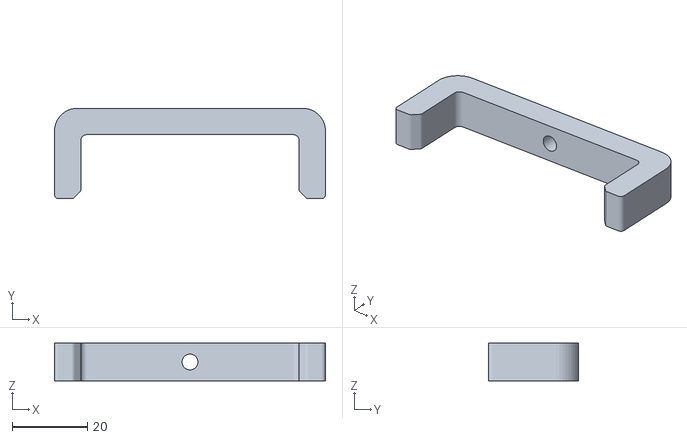
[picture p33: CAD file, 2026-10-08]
hardware/stl-print-ready/Claw2.stl
72.0 x 24.0 x 10.0

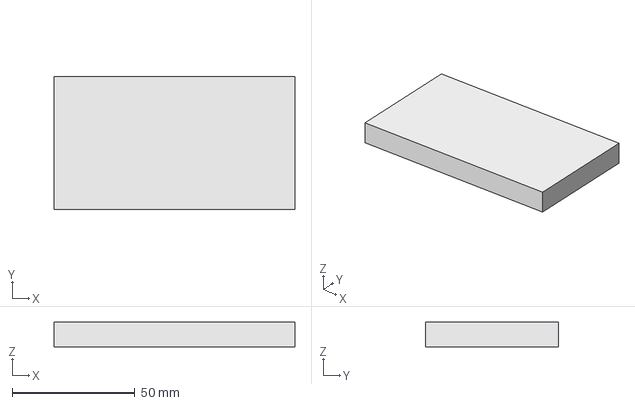
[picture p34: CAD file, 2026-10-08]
hardware/freecad-source/claw.FCStd
98.0 x 54.0 x 10.0 mm

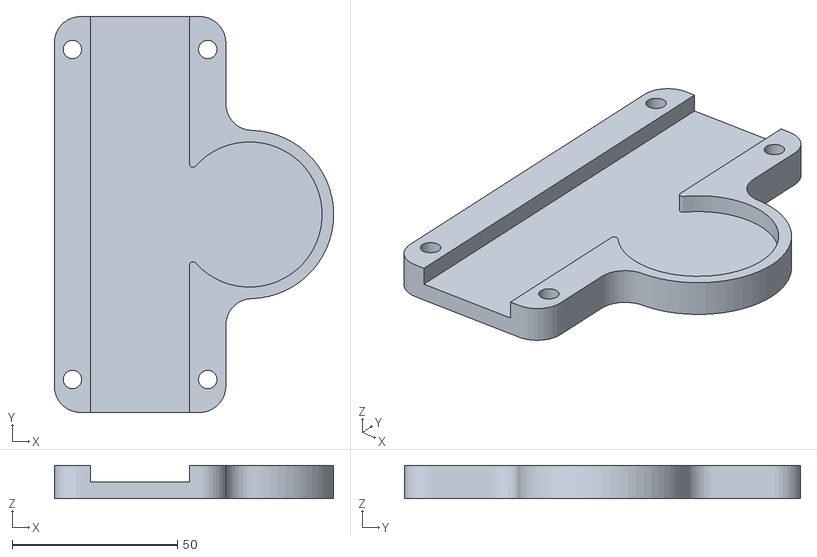
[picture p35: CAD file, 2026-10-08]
hardware/stl-print-ready/Base-bottom.stl
84.7 x 120.0 x 10.0

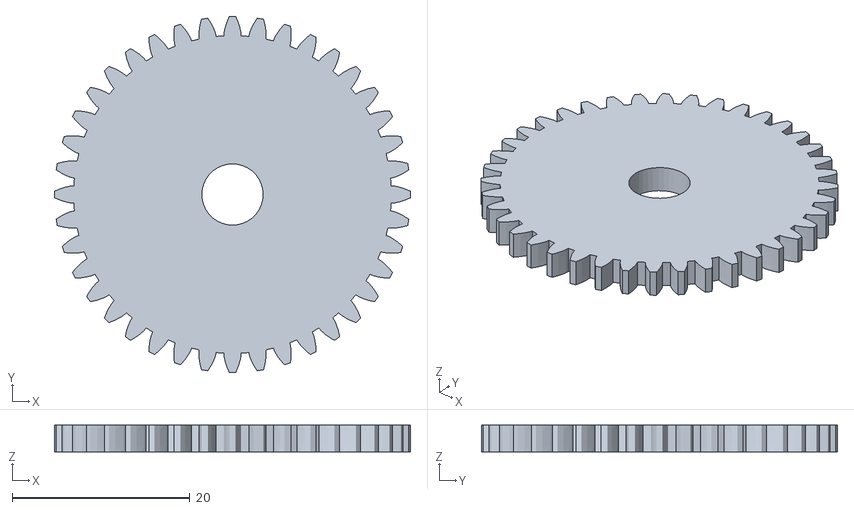
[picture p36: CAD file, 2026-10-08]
hardware/stl-print-ready/Gear.stl
40.1 x 40.1 x 3.00

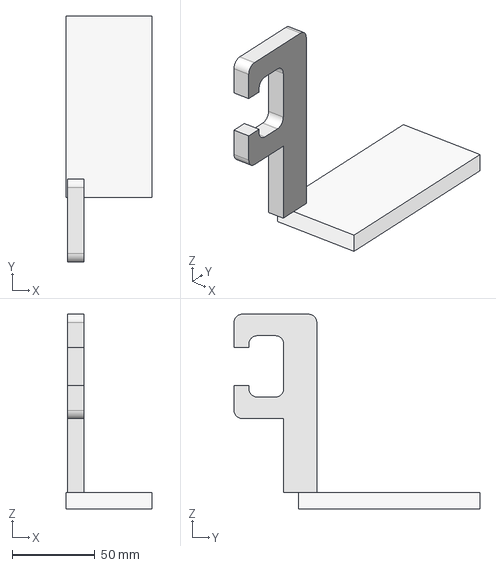
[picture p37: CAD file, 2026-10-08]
hardware/freecad-source/turret.FCStd
52.0 x 148.5 x 117.5 mm
Stock

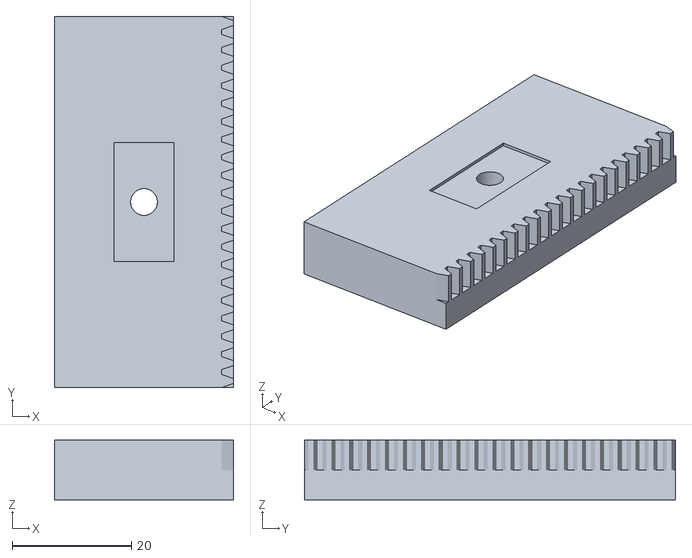
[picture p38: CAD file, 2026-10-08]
hardware/stl-print-ready/Rack.stl
30.0 x 62.2 x 10.0

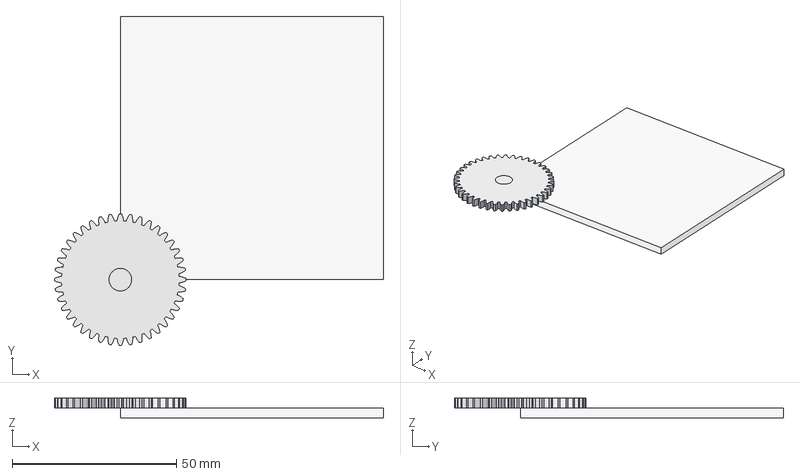
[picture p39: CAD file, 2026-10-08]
hardware/freecad-source/gear.FCStd
100.2 x 100.2 x 6.00 mm
InvoluteGear
Gear
Stock

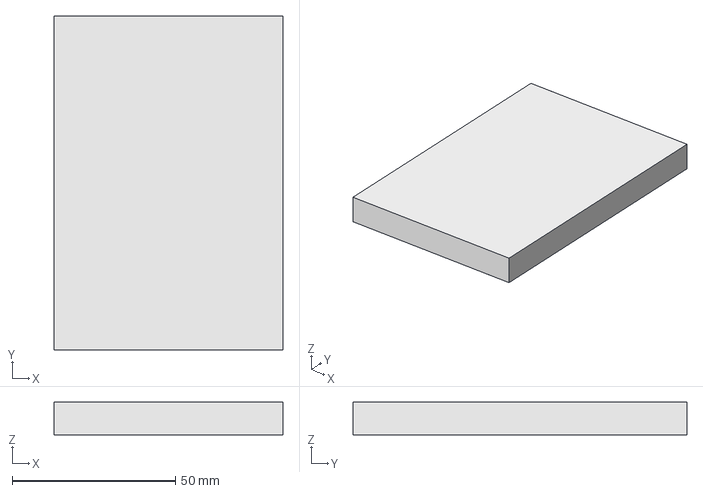
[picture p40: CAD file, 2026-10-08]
hardware/freecad-source/rack.FCStd
70.0 x 102.2 x 10.0 mm

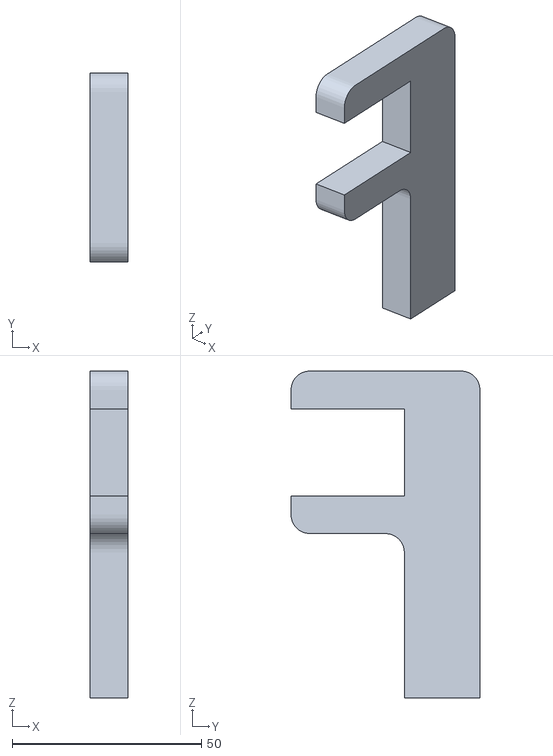
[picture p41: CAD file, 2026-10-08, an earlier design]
archive/hardware/stl-first-export/turret.stl
10.0 x 50.0 x 86.5

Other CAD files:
hardware/freecad-source/base-bottom (1).FCStd
archive/upstream-reference/Arduino-RubikSolver/CAD/2D/rubik_bot_pieces.FCStd
archive/upstream-reference/Arduino-RubikSolver/CAD/3D/base-top.FCStd
archive/upstream-reference/Arduino-RubikSolver/CAD/Final cuts/base-bottom.FCStd
archive/hardware/stl-first-export/base-bottom.stl
archive/hardware/stl-first-export/base-top.stl
archive/hardware/stl-first-export/claw.stl
archive/hardware/stl-first-export/cube.stl
archive/hardware/stl-first-export/gear.stl
archive/hardware/stl-first-export/rack.stl
archive/upstream-reference/Arduino-RubikSolver/CAD/2D/arduino_UNO.FCStd
archive/upstream-reference/Arduino-RubikSolver/CAD/2D/gear.FCStd
archive/upstream-reference/Arduino-RubikSolver/CAD/2D/involute_gear_3x32.FCStd
archive/upstream-reference/Arduino-RubikSolver/CAD/2D/involute_gear_3x40.FCStd
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

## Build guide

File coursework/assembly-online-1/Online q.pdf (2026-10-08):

January 2025 CSE 316
Online on the 8086 Assembly Language Subsections: A1

You need to print the following pattern. You must take input (n) from the user. Where the input
(n) will be, 0<n<10.

For n=3

###1

##12

#123

For n=4

####1

###12

##123

#1234

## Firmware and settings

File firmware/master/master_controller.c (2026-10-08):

/*
 * ============================================================================
 * MASTER CONTROLLER (MASTER_CONTROLLER.C) - V3 - Refactored
 * ============================================================================
 *
 * This is the MASTER ATmega32. It is the "brain" of the operation.
 *
 * RESPONSIBILITIES:
 * 1. Listens for all commands from the user via the HC-05 Bluetooth module.
 * 2. Controls the four TOP motors directly based on single-character commands.
 * 3. Controls the four BASE motors via 4-wire digital communication to the Slave.
 *
 * HARDWARE:
 * - HC-05 connected to the Hardware USART (PD0/RX, PD1/TX).
 * - Top motors connected to hardware PWM pins (PB3, PD4, PD5, PD7).
 * - 4 digital output pins (PC0, PC1, PC2, PC3) connected to Slave input pins.
 * - Must share a common GND with the Slave ATmega32.
 *
 * COMMAND PROTOCOL:
 * - Top Motors (1 char): F/f, B/b, L/l, R/r (uppercase=0deg, lowercase=90deg)
 * - Base Motors (1 char): W/w, X/x, Y/y, Z/z (uppercase=min, lowercase=max)
 * - Base communication: HIGH=max position, LOW=min position on each pin
 */

#define F_CPU 1000000UL

#include <avr/io.h>
#include <util/delay.h>
#include <stdlib.h>

// --- HARDWARE USART (for Bluetooth) ---
#define HW_BAUD_RATE 9600
#define HW_UBRR_VALUE ((F_CPU / (8UL * HW_BAUD_RATE)) - 1)

// --- BASE MOTOR CONTROL PINS (Master->Slave communication) ---
// These pins will be HIGH for max position, LOW for min position
#define BASE_FRONT_PIN   PC0
#define BASE_BACK_PIN    PC1
#define BASE_LEFT_PIN    PA2
#define BASE_RIGHT_PIN   PA3


// --- TOP MOTOR CALIBRATION VALUES ---
#define FRONT_MOTOR_0_DEG   75
#define FRONT_MOTOR_90_DEG  210
#define BACK_MOTOR_0_DEG    78
#define BACK_MOTOR_90_DEG   204
#define LEFT_MOTOR_0_DEG    7
#define LEFT_MOTOR_90_DEG   24
#define RIGHT_MOTOR_0_DEG   8
#define RIGHT_MOTOR_90_DEG  24

// --- Function Prototypes ---
void hw_usart_init(void);
void hw_usart_transmit_string(const char* str);
char hw_usart_receive_char(void);
void setup_all(void);

// Top Motor Functions
void Top_Front_0_Deg(void);
void Top_Front_90_Deg(void);
void Top_Back_0_Deg(void);
void Top_Back_90_Deg(void);
void Top_Left_0_Deg(void);
void Top_Left_90_Deg(void);
void Top_Right_0_Deg(void);
void Top_Right_90_Deg(void);

// Base Motor Functions
void Base_Front_Min(void);
void Base_Front_Max(void);
void Base_Back_Min(void);
void Base_Back_Max(void);
void Base_Left_Min(void);
void Base_Left_Max(void);
void Base_Right_Min(void);
void Base_Right_Max(void);

void L1(void);
void L2(void);
void L3(void);

void F1(void);
void F2(void);
void F3(void);

void R1(void);
void R2(void);
void R3(void);

void B1(void);
void B2(void);
void B3(void);

void U1(void);
void U2(void);
void U3(void);

void D1(void);
void D2(void);
void D3(void);

void Rotate_top();
void Rotate_bottom();


void execute_sequence(const char* sequence) {
	const char* p = sequence; // Use a pointer to traverse the string

	while (*p != '\0' && *p != '(') {
		// 1. Skip any whitespace characters (spaces, tabs, etc.)
		while (*p == ' ' || *p == '\t' || *p == '\r' || *p == '\n') {
			p++;
		}

		// Check if we've reached the end or the stop character after skipping spaces
		if (*p == '\0' || *p == '(') {
			break;
		}

		// 2. We should now be at the start of a command.
		// Check for a valid two-character command.
		if (*p != '\0' && *(p + 1) != '\0' && *(p + 1) != ' ') {
			char command = *p;
			char number  = *(p + 1);

			// Call the appropriate function based on the command pair
			if      (command == 'L' && number == '1') { L1(); }
			else if (command == 'L' && number == '2') { L2(); }
			else if (command == 'L' && number == '3') { L3(); }
			else if (command == 'R' && number == '1') { R1(); }
			else if (command == 'R' && number == '2') { R2(); }
			else if (command == 'R' && number == '3') { R3(); }
			else if (command == 'F' && number == '1') { F1(); }
			else if (command == 'F' && number == '2') { F2(); }
			else if (command == 'F' && number == '3') { F3(); }
			else if (command == 'B' && number == '1') { B1(); }
			else if (command == 'B' && number == '2') { B2(); }
			else if (command == 'B' && number == '3') { B3(); }
			else if (command == 'U' && number == '1') { U1(); }
			else if (command == 'U' && number == '2') { U2(); }
			else if (command == 'U' && number == '3') { U3(); }
			else if (command == 'D' && number == '1') { D1(); }
			else if (command == 'D' && number == '2') { D2(); }
			else if (command == 'D' && number == '3') { D3(); }

			
			// Move pointer past the two characters of the executed command
			p += 2;
			} else {
			// Invalid format (e.g., a single character at the end), so stop.
			break;
		}
	}
}



int main(void) {
	const char* solve_sequence = "F2 U3 F2 U3 B2 D1 L2 U2 F2 L1 B3 L1 F3 U1 B3 D1 L3 F3 R1 B1 (20f)";
    setup_all();

    // Initialize top motors to 90 degrees (Clockwise position)
    Base_Right_Min();
    Base_Left_Min();
    Base_Back_Min();
    Base_Front_Min();
    Top_Front_90_Deg();
    Top_Back_90_Deg();
    Top_Left_90_Deg();
    Top_Right_90_Deg();
	_delay_ms(10000);
    Base_Back_Max();
    _delay_ms(2000);
    Base_Front_Max();
    _delay_ms(2000);
    Base_Right_Max();
    _delay_ms(2000);
    Base_Left_Max();
    _delay_ms(2000);
    hw_usart_transmit_string("\r\n--- Master Controller Ready ---\r\n");
	
	//U3();
	

    while (1) {
        // Wait for a command character from Bluetooth
        char cmd = hw_usart_receive_char();

        switch (cmd) {
            // --- TOP MOTOR COMMANDS (Anti-Clockwise) ---
            case 'F': Top_Front_0_Deg(); break;
            case 'B': Top_Back_0_Deg();  break;
            case 'L': Top_Left_0_Deg(); break;
            case 'R': Top_Right_0_Deg();  break;
			case 'A': U3(); break;
            case 'S':
            hw_usart_transmit_string("Executing solve sequence...\r\n");
            execute_sequence(solve_sequence);
			            hw_usart_transmit_string("Sequence complete.\r\n");
			            break;
			            
            // --- TOP MOTOR COMMANDS (Clockwise) ---
            case 'f': Top_Front_90_Deg(); break;
            case 'b': Top_Back_90_Deg();  break;
            case 'l': Top_Left_90_Deg(); break;
            case 'r': Top_Right_90_Deg(); break;

            // --- BASE MOTOR COMMANDS (Min Position) ---
            case 'W': Base_Front_Min(); break;
            case 'X': Base_Back_Min(); break;
            case 'Y': Base_Left_Min(); break;
            case 'Z': Base_Right_Min(); break;

            // --- BASE MOTOR COMMANDS (Max Position) ---
            case 'w': Base_Front_Max(); break;
            case 'x': Base_Back_Max(); break;
            case 'y': Base_Left_Max(); break;
            case 'z': Base_Right_Max(); break;

            default:
                hw_usart_transmit_string("Unknown command.\r\n");
                break;
        }
    }
    return 0;
}

/**
 * @brief Initializes all hardware components for the Master MCU.
 */
void setup_all(void) {
    // --- Pin Setup ---
    // Top motor pins as outputs
    DDRD |= (1 << PD4) | (1 << PD5) | (1 << PD7);
    DDRB |= (1 << PB3);
    // Hardware USART TX pin (for Bluetooth) as output
    DDRD |= (1 << PD1);
    // Base motor control pins as outputs
    DDRC |= (1 << BASE_FRONT_PIN) | (1 << BASE_BACK_PIN);
    DDRA |= (1 << BASE_LEFT_PIN) | (1 << BASE_RIGHT_PIN);

    // --- Hardware USART Init ---
    hw_usart_init();

    // --- Timer Setup ---
    // Timer 1 (~61Hz) for PD4, PD5
    TCCR1A = (1 << WGM11) | (1 << COM1A1) | (1 << COM1B1);
    TCCR1B = (1 << WGM13) | (1 << WGM12) | (1 << CS11);
    ICR1 = 2048;
    // Timer 2 (~61Hz) for PD7
    TCCR2 = (1 << WGM21) | (1 << WGM20) | (1 << COM21) | (1 << CS22);
    // Timer 0 (~61Hz) for PB3
    TCCR0 = (1 << WGM01) | (1 << WGM00) | (1 << COM01) | (1 << CS01) | (1 << CS00);
}

// --- Standard Hardware USART Functions ---

void hw_usart_init(void) {
    UBRRH = (uint8_t)(HW_UBRR_VALUE >> 8);
    UBRRL = (uint8_t)HW_UBRR_VALUE;
    UCSRA = (1 << U2X);
    UCSRB = (1 << RXEN) | (1 << TXEN);
    UCSRC = (1 << URSEL) | (1 << UCSZ1) | (1 << UCSZ0);
}

void hw_usart_transmit_char(char data) {
    while (!(UCSRA & (1 << UDRE)));
    UDR = data;
}

void hw_usart_transmit_string(const char* str) {
    while (*str) {
        hw_usart_transmit_char(*str++);
    }
}

char hw_usart_receive_char(void) {
    while (!(UCSRA & (1 << RXC)));
    return UDR;
}

// --- TOP MOTOR FUNCTIONS ---

/**
 * @brief Sets the Top Front motor to 0 degrees (Anti-Clockwise).
 */
void Top_Front_0_Deg(void) {
    OCR1B = FRONT_MOTOR_0_DEG;
    hw_usart_transmit_string("Top Front -> 0 deg\r\n");
}

/**
 * @brief Sets the Top Front motor to 90 degrees (Clockwise).
 */
void Top_Front_90_Deg(void) {
    OCR1B = FRONT_MOTOR_90_DEG;
    hw_usart_transmit_string("Top Front -> 90 deg\r\n");
}

/**
 * @brief Sets the Top Back motor to 0 degrees (Anti-Clockwise).
 */
void Top_Back_0_Deg(void) {
    OCR1A = BACK_MOTOR_0_DEG;
    hw_usart_transmit_string("Top Back -> 0 deg\r\n");
}

/**
 * @brief Sets the Top Back motor to 90 degrees (Clockwise).
 */
void Top_Back_90_Deg(void) {
    OCR1A = BACK_MOTOR_90_DEG;
    hw_usart_transmit_string("Top Back -> 90 deg\r\n");
}

/**
 * @brief Sets the Top Left motor to 0 degrees (Anti-Clockwise).
 */
void Top_Left_0_Deg(void) {
    OCR2 = LEFT_MOTOR_0_DEG;
    hw_usart_transmit_string("Top Left -> 0 deg\r\n");
}

/**
 * @brief Sets the Top Left motor to 90 degrees (Clockwise).
 */
void Top_Left_90_Deg(void) {
    OCR2 = LEFT_MOTOR_90_DEG;
    hw_usart_transmit_string("Top Left -> 90 deg\r\n");
}

/**
 * @brief Sets the Top Right motor to 0 degrees (Anti-Clockwise).
 */
void Top_Right_0_Deg(void) {
    OCR0 = RIGHT_MOTOR_0_DEG;
    hw_usart_transmit_string("Top Right -> 0 deg\r\n");
}

/**
 * @brief Sets the Top Right motor to 90 degrees (Clockwise).
 */
void Top_Right_90_Deg(void) {
    OCR0 = RIGHT_MOTOR_90_DEG;
    hw_usart_transmit_string("Top Right -> 90 deg\r\n");
}

// --- BASE MOTOR FUNCTIONS ---

/**
 * @brief Sets the Base Front motor to its minimum position.
 */
void Base_Front_Min(void) {
    PORTC &= ~(1 << BASE_FRONT_PIN);
    hw_usart_transmit_string("Base Front -> Min\r\n");
}

/**
 * @brief Sets the Base Front motor to its maximum position.
 */
void Base_Front_Max(void) {
    PORTC |= (1 << BASE_FRONT_PIN);
    hw_usart_transmit_string("Base Front -> Max\r\n");
}

/**
 * @brief Sets the Base Back motor to its minimum position.
 */
void Base_Back_Min(void) {
    PORTC &= ~(1 << BASE_BACK_PIN);
    hw_usart_transmit_string("Base Back -> Min\r\n");
}


/**
 * @brief Sets the Base Back motor to its maximum position.
 */
void Base_Back_Max(void) {
    PORTC |= (1 << BASE_BACK_PIN);
    hw_usart_transmit_string("Base Back -> Max\r\n");
}

/**
 * @brief Sets the Base Left motor to its minimum position.
 */
void Base_Left_Min(void) {
    PORTA &= ~(1 << BASE_LEFT_PIN);hw_usart_transmit_string("Base Left -> Min\r\n");
}

/**
 * @brief Sets the Base Left motor to its maximum position.
 */
void Base_Left_Max(void) {
    PORTA |= (1 << BASE_LEFT_PIN);hw_usart_transmit_string("Base Left -> Max\r\n");
}

/**
 * @brief Sets the Base Right motor to its minimum position.
 */
void Base_Right_Min(void) {
    PORTA &= ~(1 << BASE_RIGHT_PIN);hw_usart_transmit_string("Base Right -> Min\r\n");
}

/**
 * @brief Sets the Base Right motor to its maximum position.
 */
void Base_Right_Max(void) {
    PORTA |= (1 << BASE_RIGHT_PIN);hw_usart_transmit_string("Base Right -> Max\r\n");
}

void R3(void)
{
	Top_Right_0_Deg();
	_delay_ms(900);
	Base_Right_Min();
	_delay_ms(900);
	Top_Right_90_Deg();
	_delay_ms(900);
	Base_Right_Max();
	_delay_ms(900);
}
void R2(void)
{
	Top_Right_0_Deg();
	_delay_ms(900);
	Base_Right_Min();
	_delay_ms(900);
	Top_Right_90_Deg();
	_delay_ms(900);
	Base_Right_Max();
	_delay_ms(900);
	Top_Right_0_Deg();
	_delay_ms(900);
	Base_Right_Min();
	_delay_ms(900);
	Top_Right_90_Deg();
	_delay_ms(900);
	Base_Right_Max();
	_delay_ms(900);
}
void R1(void)
{
	Base_Right_Min();
	_delay_ms(900);
	Top_Right_0_Deg();
	_delay_ms(900);
	Base_Right_Max();
	_delay_ms(900);
	Top_Right_90_Deg();
	_delay_ms(900);
}
void B3(void)
{
	Top_Back_0_Deg();
	_delay_ms(900);
	Base_Front_Min();
	_delay_ms(900);
	Top_Back_90_Deg();
	_delay_ms(900);
	Base_Front_Max();
	_delay_ms(900);
}
void B2(void)
{
	Top_Back_0_Deg();
	_delay_ms(900);
	Base_Front_Min();
	_delay_ms(900);
	Top_Back_90_Deg();
	_delay_ms(900);
	Base_Front_Max();
	_delay_ms(900);
	Top_Back_0_Deg();
	_delay_ms(900);
	Base_Front_Min();
	_delay_ms(900);
	Top_Back_90_Deg();
	_delay_ms(900);
	Base_Front_Max();
	_delay_ms(900);
}
void B1(void)
{
	Base_Front_Min();
	_delay_ms(900);
	Top_Back_0_Deg();
	_delay_ms(900);
	Base_Front_Max();
	_delay_ms(900);
	Top_Back_90_Deg();
	_delay_ms(900);
}
void F3(void)
{
	Top_Front_0_Deg();
	_delay_ms(900);
	Base_Back_Min();
	_delay_ms(900);
	Top_Front_90_Deg();
	_delay_ms(900);
	Base_Back_Max();
	_delay_ms(900);
}
void F2(void)
{
	Top_Front_0_Deg();
	_delay_ms(900);
	Base_Back_Min();
	_delay_ms(900);
	Top_Front_90_Deg();
	_delay_ms(900);
	Base_Back_Max();
	_delay_ms(900);
	Top_Front_0_Deg();
	_delay_ms(900);
	Base_Back_Min();
	_delay_ms(900);
	Top_Front_90_Deg();
	_delay_ms(900);
	Base_Back_Max();
	_delay_ms(900);
}
void F1(void)
{
	Base_Back_Min();
	_delay_ms(900);
	Top_Front_0_Deg();
	_delay_ms(900);
	Base_Back_Max();
	_delay_ms(900);
	Top_Front_90_Deg();
	_delay_ms(900);
}
void L3(void)
{
	Top_Left_0_Deg();
	_delay_ms(900);
	Base_Left_Min();
	_delay_ms(900);
	Top_Left_90_Deg();
	_delay_ms(900);
	Base_Left_Max();
	_delay_ms(900);
}

void L2(void)
{
	Top_Left_0_Deg();
	_delay_ms(900);
	Base_Left_Min();
	_delay_ms(900);
	Top_Left_90_Deg();
	_delay_ms(900);
	Base_Left_Max();
	_delay_ms(900);
	Top_Left_0_Deg();
	_delay_ms(900);
	Base_Left_Min();
	_delay_ms(900);
	Top_Left_90_Deg();
	_delay_ms(900);
	Base_Left_Max();
	_delay_ms(900);
}
void L1(void)
{
	Base_Left_Min();
	_delay_ms(900);
	Top_Left_0_Deg();
	_delay_ms(900);
	Base_Left_Max();
	_delay_ms(900);
	Top_Left_90_Deg();
	_delay_ms(900);
}


void Rotate_top()
   {
	Base_Left_Min();
	_delay_ms(900);
	Top_Left_0_Deg();
	_delay_ms(900);
	Base_Left_Max();
	_delay_ms(900);
	Base_Front_Min();
	_delay_ms(900);
	Base_Back_Min();
	_delay_ms(900);
	Top_Left_90_Deg();
	Top_Right_0_Deg();
	_delay_ms(900);
	Base_Front_Max();
	_delay_ms(900);
	Base_Back_Max();
	_delay_ms(900);
	Base_Right_Min();
	_delay_ms(900);
	Top_Right_90_Deg();
	_delay_ms(900);
	Base_Right_Max();
	_delay_ms(900);
}

void Rotate_bottom()
{
	Base_Right_Min();
	_delay_ms(900);
	Top_Right_0_Deg();
	_delay_ms(900);
	Base_Right_Max();
	_delay_ms(900);
	Base_Front_Min();
	_delay_ms(900);
	Base_Back_Min();
	_delay_ms(900);
	Top_Left_0_Deg();
	Top_Right_90_Deg();
	_delay_ms(900);
	Base_Front_Max();
	_delay_ms(900);
	Base_Back_Max();
	_delay_ms(900);
	Base_Left_Min();
	_delay_ms(900);
	Top_Left_90_Deg();
	_delay_ms(900);
	Base_Left_Max();
	_delay_ms(900);
}

void U1(void)
{
	Rotate_top();
	F1();
	Rotate_bottom();
}

void U2(void)
{
	Rotate_top();
	F2();
	Rotate_bottom();
}

void U3(void)
{
	Rotate_top();
	F3();
	Rotate_bottom();
}
void D1(void)
{
	Rotate_bottom();
	F1();
	Rotate_top();
}

void D2(void)
{
	Rotate_bottom();
	F2();
	Rotate_top();
}

void D3(void)
{
	Rotate_bottom();
	F3();
	Rotate_top();
}

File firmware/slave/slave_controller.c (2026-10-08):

/*
 * ============================================================================
 * SLAVE CONTROLLER (SLAVE_CONTROLLER.C) - V2
 * ============================================================================
 *
 * This is the SLAVE ATmega32. It is responsible for controlling the base motors.
 *
 * RESPONSIBILITIES:
 * 1. Monitors 4 input pins from the Master ATmega32.
 * 2. Controls the four BASE motors based on the digital signals received.
 *
 * HARDWARE:
 * - 4 input pins (PC0, PC1, PC2, PC3) connected to Master's output pins.
 * - Must share a common GND with the Master ATmega32.
 * - Base motors connected to hardware PWM pins (PB3, PD4, PD5, PD7).
 *
 * CONTROL PROTOCOL:
 * - HIGH signal = Motor moves to MAX position
 * - LOW signal = Motor moves to MIN position
 * - PC0 = Base Front Motor
 * - PC1 = Base Back Motor
 * - PC2 = Base Left Motor
 * - PC3 = Base Right Motor
 */

#define F_CPU 1000000UL

#include <avr/io.h>
#include <util/delay.h>
#include <stdlib.h>

// --- INPUT PINS (from Master) ---
#define MASTER_FRONT_PIN  PC0
#define MASTER_BACK_PIN   PC1
#define MASTER_LEFT_PIN   PC2
#define MASTER_RIGHT_PIN  PC3

// ============================================================================
// !!! IMPORTANT: CALIBRATION REQUIRED !!!
// You must replace these placeholder values with the correct values for your
// four BASE motors. These values correspond to the MIN and MAX positions.
// ============================================================================


// Front Motor (PD4 - Timer1B)
#define BASE_FRONT_MIN   70 // Placeholder for 0 degrees
#define BASE_FRONT_MAX   230 // Placeholder for 60 degrees

// Back Motor (PD5 - Timer1A)
#define BASE_BACK_MIN    120 // Placeholder for 0 degrees
#define BASE_BACK_MAX    280 // Placeholder for 60 degrees

// Left Motor (PD7 - Timer2)
#define BASE_LEFT_MIN    10 // Placeholder for 0 degrees
#define BASE_LEFT_MAX    30 // Placeholder for 60 degrees

// Right Motor (PB3 - Timer0)
#define BASE_RIGHT_MIN   10 // Placeholder for 0 degrees
#define BASE_RIGHT_MAX   30 // Placeholder for 60 degrees


// --- Function Prototypes ---
void setup_all(void);

int main(void) {
    setup_all();

    // Initialize base motors to their minimum position
    OCR1B = BASE_FRONT_MIN; // Base Front
    OCR1A = BASE_BACK_MIN;  // Base Back
    OCR2  = BASE_LEFT_MIN;  // Base Left
    OCR0  = BASE_RIGHT_MIN; // Base Right

    while (1) {
        // Read the input pins from Master and control motors accordingly
        
        // Base Front Motor (controlled by PC0)
        if (PINC & (1 << MASTER_FRONT_PIN)) {
            OCR1B = BASE_FRONT_MAX; // HIGH = Max position
        } else {
            OCR1B = BASE_FRONT_MIN; // LOW = Min position
        }
        
        // Base Back Motor (controlled by PC1)
        if (PINC & (1 << MASTER_BACK_PIN)) {
            OCR1A = BASE_BACK_MAX;
        } else {
            OCR1A = BASE_BACK_MIN;
        }
        
        // Base Left Motor (controlled by PC2)
        if (PINC & (1 << MASTER_LEFT_PIN)) {
            OCR2 = BASE_LEFT_MAX;
        } else {
            OCR2 = BASE_LEFT_MIN;
        }
        
        // Base Right Motor (controlled by PC3)
        if (PINC & (1 << MASTER_RIGHT_PIN)) {
            OCR0 = BASE_RIGHT_MAX;
        } else {
            OCR0 = BASE_RIGHT_MIN;
        }
        
        // Small delay to avoid excessive polling
        _delay_ms(10);
    }
    return 0;
}

/**
 * @brief Initializes all hardware components for the Slave MCU.
 */
void setup_all(void) {
    // --- Pin Setup ---
    // Base motor pins as outputs
    DDRD |= (1 << PD4) | (1 << PD5) | (1 << PD7);
    DDRB |= (1 << PB3);
    // Input pins from Master (PC0, PC1, PC2, PC3) - already inputs by default
    DDRC &= ~((1 << MASTER_FRONT_PIN) | (1 << MASTER_BACK_PIN) | (1 << MASTER_LEFT_PIN) | (1 << MASTER_RIGHT_PIN));

    // --- Timer Setup ---
    // Timer 1 (~61Hz) for PD4 (Base Front), PD5 (Base Back)
    TCCR1A = (1 << WGM11) | (1 << COM1A1) | (1 << COM1B1);
    TCCR1B = (1 << WGM13) | (1 << WGM12) | (1 << CS11);
    ICR1 = 2048;
    // Timer 2 (~61Hz) for PD7 (Base Left)
    TCCR2 = (1 << WGM21) | (1 << WGM20) | (1 << COM21) | (1 << CS22);
    // Timer 0 (~61Hz) for PB3 (Base Right)
    TCCR0 = (1 << WGM01) | (1 << WGM00) | (1 << COM01) | (1 << CS01) | (1 << CS00);
}

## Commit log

2026-10-08 Initial commit: SCRAMBLE automated Rubik's Cube solver
    Organized repo for the CSE 316 project: ATmega32 master/slave firmware,
    Android scanner app, Kociemba two-phase solver server, 3D-printable
    hardware, plus archived explorations and unrelated coursework.
    [Base-bottom.stl, Base-top.stl, Claw2.stl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]
2026-10-08 Tighten README: concise, polished copy without repeated links
